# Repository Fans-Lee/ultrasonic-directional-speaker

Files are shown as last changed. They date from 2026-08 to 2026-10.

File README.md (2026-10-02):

**本项目没有参考任何开源项目，包括硬件实现、3D打印建模、软件实现。仅在作品构思阶段参考了一些现有成品的原理及作者反馈的问题。**

# 超声参量阵定向音响

> 文档版本：v5.3（2026-10-02）
> 当前实施基线：120 个换能器、12 路 TC4428 功率驱动、GPIO4 单相位扇出、40 kHz 复阻抗配组、二维机械云台和电脑视觉控制。

本项目将可听音频调制到 40 kHz 超声载波，通过 120 阵元同相发射获得窄声束，并由视觉跟踪和二维云台改变指向。当前版本不做电子相位转向或逐阵元聚焦。

```text
摄像头 → YOLO 人体检测 / ByteTrack 跟踪 → PI 控制 → 二维云台
音源   → 电脑端 DSP → 8 kHz PCM → ESP32 调制 → GPIO4
GPIO4  → SN74HC125 扇出 12 路 → 12 片 TC4428 → 12 组已配组的 TCT40-16T
```

120 只换能器逐只测量 40 kHz 复阻抗 `Z = R + jX`。分组时将容性与感性单元混合，并用导纳求和计算每组 10 只并联后的等效负载，使 12 路的虚部和幅值尽量接近。阵面上同时交错放置容性与感性单元，避免同类单元集中在局部区域。详细原理和施工要求见 [`docs/09-当前120阵元单GPIO接线.md`](docs/09-当前120阵元单GPIO接线.md)。
## 0.原创性说明

本项目没有参考任何开源项目，包括硬件实现、3D打印建模、软件实现。仅在作品构思阶段参考了一些现有成品的原理及作者反馈的问题。

## 1. 项目入口点

| 入口 | 文件 | 用途 |
|---|---|---|
| 桌面端主程序 | `src/vision_gimbal/__main__.py` | PySide6 UI、人体跟踪、云台、实时音频和声场显示 |
| 桌面端组合根 | `src/vision_gimbal/bootstrap.py` | 组装摄像头、YOLO、控制、串口、音频和 UI |
| 主配置 | `configs/vision_gimbal.toml` | 摄像头、模型、云台、串口、音频与可选声场参数 |
| ESP32 正式固件 | `src/full_size/full_size.ino` | 120 阵元单 GPIO 调制、二维舵机、Flash/实时音频和二进制协议 |
| 独立音频测试 | `utils/mic_stream_cli.py` | 不启动视觉和 UI，单独测试麦克风/电脑音频串流 |
| 文件串流诊断 | `utils/audio_stream_probe.py` | 把内置 PCM 原字节发给 ESP32，排查传输与调制问题 |
| Flash 音频转换 | `utils/wav_to_audio_header.py` | 把 PCM WAV 转为固件的 `audio_data.h` |
| 离线声学校准 | `utils/audio_calibration/calibrate.py` | 生成实验 PCM、拟合固定非线性模型、评估和预失真；不启动 Qt 或串口 |
| 单音录音试训 | `utils/audio_calibration/tone_pilot.py` | 对无配对输入的单音 WAV 拟合录音谐波轮廓；详见 `docs/16-单音录音试训.md` |
| 手机录音带通诊断 | `utils/audio_calibration/bandpass_wav.py` | 离线保留 250–3000 Hz，输出滤波 WAV 与频带电平报告；见 `docs/16-手机录音带通诊断.md` |

正式桌面端使用 `python -m vision_gimbal`。`src/cv_test_deprecated` 和 `src/esp32_s3_4x3_min_test_deprecated` 只是历史实现，不是当前入口。

## 2. 运行环境

电脑端建议使用：

- Windows 10/11；“静音无关回环”音源使用 Windows WASAPI；
- Python 3.11，项目支持 Python 3.10～3.12；
- [uv](https://docs.astral.sh/uv/)；
- UVC USB 摄像头；
- 连接硬件时需要 ESP32-S3 的 COM 口。

从仓库根目录同步锁定依赖：

```powershell
uv sync --locked --python 3.11
```

这会同时安装测试依赖。默认为 CPU 推理，并关闭可选的深度/声场分析。

### 可选推理后端

NVIDIA CUDA：

```powershell
uv sync --locked --python 3.11 --extra cuda
```

Intel XPU：

```powershell
uv sync --locked --python 3.11 --extra xpu
```

`cuda` 和 `xpu` 互斥，不能同时安装。`uv sync` 会以本次命令指定的 extra 同步环境，以后重新同步时应重复写出仍需要的 extra。

## 3. 启动桌面端

### 3.1 只运行视觉和云台仿真

在 PowerShell 中从仓库根目录执行：

```powershell
$env:PYTHONPATH = ".\src"
uv run python -m vision_gimbal --camera-index 0
```

这种方式不打开串口，但会运行摄像头、人体检测、目标选择和控制计算。如果第一个摄像头不是索引 `0`，修改 `--camera-index`。

### 3.2 连接 ESP32 完整启动

先烧录第 5 节的正式固件，然后确认 Windows 设备管理器中的 COM 口。例如 ESP32 是 `COM5`：

```powershell
$env:PYTHONPATH = ".\src"
uv run python -m vision_gimbal --camera-index 0 --serial-port COM5
```

可选的命令行覆盖：

```text
--config PATH       指定 TOML 配置
--serial-port COM5  指定 ESP32 串口
--baudrate 460800   覆盖串口波特率
--camera-index 0    覆盖摄像头索引
--device cpu        覆盖 YOLO 推理设备，也可使用 cuda:0 或 xpu:0
```

程序启动后：

1. 在追踪画面中单击人体框；
2. 单击“开始追踪”才会进入自动云台闭环；
3. 停止追踪时可用 `W/A/S/D` 手动控制；
4. 串口连接后选择音源，再单击“开始音频链路”。

### 连续调节音量

先烧录本仓库最新的 `src/full_size/full_size.ino` 固件，再启动桌面程序。串口连接并完成协议握手后，“音频与超声阵列”面板中的“主音量”滑块会启用；拖动它可在播放中调节麦克风、立体声混音或电脑声音，音频链路不会重启。默认音量为 50%，可在 `configs/vision_gimbal.toml` 的 `[audio.volume] default_percent` 修改。

0% 会在短暂渐变后关闭 GPIO4 超声 PWM；100% 等于原有最大音频调制幅度。滑块只衰减音频，不改变固定载波和测试纯音命令。界面的频谱与可选录音仍显示音量调节前的输入音频。若面板提示“固件需更新”，请先烧录新固件；旧固件的音频启动会被禁止，以免设定音量未生效。

不用桌面程序时，可在 460800 波特率串口监视器中发送 `V30` 后按回车，把内置 Flash 音频设为 30%；再发送 `P` 播放一次或 `L` 循环播放。`V0` 为音量静音，`V100` 恢复原有幅度，播放过程中也可调整。此命令仅在没有桌面端二进制协议会话时使用。音量静音不等于断开 12 V 电源。

默认音源是“电脑声音（静音无关回环）”。helper 不存在或其源码更新后，程序会自动调用 `utils/build_wasapi_process_loopback.ps1`，需要 MinGW-w64 `g++` 已在 `PATH` 中。也可提前编译：

```powershell
.\utils\build_wasapi_process_loopback.ps1
```

运行期间若 Windows 音频资源重配、helper 异常退出或 PCM 管道卡住，程序会自动重建回环采集和设备音频流；真实数字静音仍按活动门限关闭阵列 PWM。

不需要 WASAPI 进程回环时，可在 UI 中改选“麦克风”或“立体声混音”。用下列命令查看 PortAudio 设备名称：

```powershell
uv run python -m sounddevice
```

### 人物再次出现时的编号

视觉流水线会为合格的人体检测框提取服饰颜色特征，并在本次运行期间维护人物编号。新轨迹会立即抽样，最多取四次合格特征确定编号；已编号的轨迹默认每 1 秒再抽样一次，Kalman 预测框不会抽样。与历史人物连续两次匹配后，新轨迹会复用原编号。身份库默认保留离开画面人物 120 秒，程序关闭后清空。

这一路径只使用 CPU 和现有 OpenCV，不需要下载模型。它主要适用于同一摄像头、同一场次且衣着未变的情况；相似衣着、强遮挡或换装时可能认错或无法认回。人物未取得可靠特征前，框上显示 `ID ?`，不能选为自动追踪目标。目标丢失超过 0.8 秒后仍会停止自动追踪；人物被再次认出时可直接点击“开始追踪”，不会自行重启云台。参数在 `configs/vision_gimbal.toml` 的 `[vision.appearance]` 中调整。

## 4. 可选的深度与声场显示

此功能只做低频率可视化，不向云台、音频或 ESP32 发送指令。默认关闭。

1. 安装 OpenVINO 可选依赖：

   ```powershell
   uv sync --locked --python 3.11 --extra spatial
   ```

2. 确认模型目录 `models/yolo26n-depth_openvino_model` 存在。
3. 在 `configs/vision_gimbal.toml` 中设置：

   ```toml
   [spatial_field]
   enabled = true

   [spatial_field.depth]
   device = "intel:gpu"
   ```

如果需要同时使用 Intel XPU 跑人体跟踪，同步时同时传入两个 extra：

```powershell
uv sync --locked --python 3.11 --extra xpu --extra spatial
```

要在 CPU 上运行声场分析，还需将 `device` 改为 `cpu`，并设置 `allow_cpu_fallback = true`。

## 5. 编译和启动 ESP32 正式固件

仓库当前的唯一正式烧录入口是：

```text
src/full_size/full_size.ino
```

当前已验证的环境为 Arduino-ESP32 3.3.10。Arduino IDE 设置：

| 选项 | 值 |
|---|---|
| Board | `ESP32S3 Dev Module` |
| Upload Speed | `115200` |
| Flash Size | `16MB` |
| PSRAM | `8MB OPI`，以实际 ESP32-S3-WROOM-1-N16R8 菜单为准 |
| USB CDC On Boot | `Disabled`（当前 CH340X 链路） |
| 串口监视器 | `460800` baud |

打开 `.ino` 后编译并上传。上电后固件会把云台指令设为逻辑 `(0,0)`，但超声 PWM 保持关闭。在不连接桌面端时，可在串口监视器发送：

```text
A            连续固定载波
T            1 kHz 包络测试
P / L        播放一次 / 循环播放 Flash 音频
0 + 回车     停止 GPIO4 切换
H            显示完整帮助
```

详细命令、烧录和首次上电步骤见 [`src/full_size/README.md`](src/full_size/README.md)；120 阵元接线以 [`docs/09-当前120阵元单GPIO接线.md`](docs/09-当前120阵元单GPIO接线.md) 为准。

## 6. 独立诊断与音频工具

只测试麦克风到 ESP32 的音频链：

```powershell
$env:PYTHONPATH = ".\src"
uv run python .\utils\mic_stream_cli.py --serial-port COM5
```

使用当前 Flash PCM 测试串口传输：

```powershell
uv run python .\utils\audio_stream_probe.py --inspect-only
uv run python .\utils\audio_stream_probe.py --serial-port COM5 --processing raw --drive standard
```

把 PCM WAV 更换为固件内置音频：

```powershell
uv run python .\utils\wav_to_audio_header.py `
  .\input.wav `
  .\src\full_size\src\data\audio_data.h
```

生成后需要重新编译和烧录 ESP32。

## 7. 测试

从仓库根目录执行：

```powershell
uv sync --locked --python 3.11
uv run python -m pytest -q
uv run python -m compileall -q src utils
```

pytest 只收集 `tests/`，不会运行两个 `_deprecated` 历史目录。

## 8. 当前文档

- [原理、公式与能力边界](docs/01-原理与公式.md)
- [120 阵元整机与硬件实施](docs/02-系统方案与硬件.md)
- [当前软件架构与接口](docs/03-软件架构.md)
- [参考资料与证据边界](docs/04-开源参考.md)
- [实施计划与分工](docs/05-计划与分工.md)
- [采购、备件与到货验收](docs/06-采购清单.md)
- [版本验收、风险与演示](docs/07-版本阶梯与风险.md)
- [历史 12 阵元原型](docs/08-当前12阵元原型.md)
- [120 阵元单 GPIO 接线](docs/09-当前120阵元单GPIO接线.md)
- [当前项目完整数据流](docs/10-当前项目完整数据流.md)
- [视觉云台跟踪系统](docs/11-视觉云台跟踪系统.md)
- [实时音源与音频流协议](docs/12-实时麦克风与音频流协议.md)
- [实时音频传输排查](docs/13-实时音频传输排查.md)
- [连续音量控制设计与实现](docs/连续音量控制设计提案.md)
- [终审答辩 PPT](docs/show/超声参量阵视觉跟随定向音响-终审答辩.pptx)

`docs/01`～`docs/07` 已按当前 120 阵元机械转向基线重写；`docs/08` 是历史 12 阵元台架记录。任何电子相控研究都必须单独标记为未来方案，不得覆盖当前施工文档。

## 9. 安全边界

- 任何改线、插拔芯片或连接示波器之前，必须物理断开 12 V 功率电源。
- 串口 `0`、关闭音频链路或停止追踪都不等于物理急停。
- MG996R 舵机使用独立 5～6 V 大电流电源，与 ESP32 共地；不得从 ESP32 3.3 V 引脚供电。
- 不要把耳朵靠近阵面，不要用手机分贝 App 判断 40 kHz 超声暴露安全。
- 首次上电必须按正式固件 README 的单片、单换能器到全阵的顺序逐级验证。

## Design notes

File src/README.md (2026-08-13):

# ESP32-S3 + 12 只 TCT40-16T：4×3 最小测试版

## 1. 分组结论

把洞洞板的长边横放，形成 4 列、3 行：

```text
正面观察阵面

 CH1    CH2    CH3    CH4
  ○      ○      ○      ○
  ○      ○      ○      ○
  ○      ○      ○      ○
```

每一列 3 只并联，由一个 LEDC 输出通道和一个 TC4428A 驱动。因此是 **4 个 LEDC 输出通道，每个控制 3 只**。严格说并不是 4 个独立的 LEDC 外设：代码让 4 个输出通道共用 LEDC Timer 0，频率基准相同。

这样做的原因：

- 每个驱动器只承担 3 只换能器的并联电容，比 5 只更轻；
- 有 4 个横向相位自由度，后续可以做左右转向；
- 3 路各带 4 只只有 3 个横向相位自由度，而且每通道负载更大；
- 这只是 1D 横向转向原型，不等于已经能做 2D 定点聚焦。

今天先让 4 路全部同相。不要在没有示波器验证 `hpoint` 和更新毛刺前直接尝试相位扫描。

## 2. 今天需要的元件

| 元件 | 数量 | 说明 |
|---|---:|---|
| ESP32-S3 自制开发板 | 1 | GPIO4、5、6、7 |
| TCT40-16T 发射换能器 | 12 | 4 列，每列 3 只并联 |
| TC4428AEPA（DIP-8） | 4 | 每列 1 片 |
| DIP-8 插座 | 4 | 建议使用，先焊插座再插芯片 |
| 10～100 Ω、1/4 W 电阻 | 4 | 每路 GPIO 输入串联；现有10 Ω可用 |
| 10 kΩ、1/4 W 电阻 | 4 | 每路 TC4428 输入下拉 |
| 100 nF、≥25 V 陶瓷电容 | 4 | 每片 TC4428 的近端去耦 |
| 4.7～10 µF、≥25 V 电容 | 4 | 每片 TC4428 的近端储能 |
| 470 µF、≥25 V 电解电容 | 1 | 四路驱动板的 12 V 总入口 |
| 10～22 Ω、0.5 W 电阻 | 4 | 初次上电的输出串联限流/阻尼，可稍降声压 |
| 12 V/5 A 中心正适配器 | 1 | 本次远用不到 5 A，但电压合适 |
| 1～2 A 保险丝和匹配保险丝座 | 1 | 装在驱动板 12 V 分支；只有 5 A 也可先用，但保护较弱 |
| 开关、接线端子、洞洞板、导线 | 若干 | 电源线 18 AWG；逻辑/短输出线 22～24 AWG |

今天不需要：谐振电感、L298N、74HC125N、74LVC125AD、旋转平台、摄像头。短线台架仍按原方案，由 ESP32-S3 的 3.3 V GPIO 直接驱动 TC4428A 输入。现有一片 74AHCT125N 恰好能缓冲 4 路，但为保持本次最小版接线不变，暂不加入；如果后续加入，必须四路一起加入。

## 3. TC4428AEPA 逐针接线

缺口朝上，从左上角 1 脚开始逆时针编号：

```text
             缺口
          ┌────────┐
 NC    1 ─┤        ├─ 8  NC
 IN_A  2 ─┤TC4428A ├─ 7  OUT_A
 GND   3 ─┤        ├─ 6  VDD (+12 V)
 IN_B  4 ─┤        ├─ 5  OUT_B
          └────────┘
```

每一路完全相同：

```text
ESP32 GPIO ──10～100 Ω──┬── pin 2 IN_A
                    ├── pin 4 IN_B
                    └──10 kΩ── GND

12 V ─────────────── pin 6 VDD
GND  ─────────────── pin 3 GND

pin 6 VDD ──||── pin 3 GND    100 nF，贴近芯片
pin 6 VDD ──|(|─ pin 3 GND    4.7～10 µF，电解正极接 VDD

pin 7 OUT_A ──10～22 Ω── 列 A 母线 ──┬── 换能器 1 的 A 脚
                                  ├── 换能器 2 的 A 脚
                                  └── 换能器 3 的 A 脚

pin 5 OUT_B ───────── 列 B 母线 ──┬── 换能器 1 的 B 脚
                                  ├── 换能器 2 的 B 脚
                                  └── 换能器 3 的 B 脚
```

注意：

- pin 2 和 pin 4 必须接同一 GPIO；TC4428A 的两路输出因此互补；
- 换能器接在 `OUT_A` 与 `OUT_B` 之间，**两端都不能接 GND**；
- 串口命令 `0` 只会停止 40 kHz 切换。由于 TC4428A 是互补输出，静态输入时两输出仍可能一高一低；改线必须关闭驱动板 12 V，不能把软件停止当作断电；
- 四列的 A/B 输出母线互不相连；只有 `+12 V` 和 `GND` 共用；
- 12 只换能器朝向一致，同一侧引脚都标为 A；所有引脚都要焊，不靠孔的夹紧力导电；
- 每片芯片的 100 nF 必须贴近 pin 6 和 pin 3，不能只在电源入口放一个大电容；
- 10～22 Ω 先装在 OUT_A 一侧即可。示波器验证稳定后才考虑用 0 Ω 跨接旁路；
- pin 1、pin 8 悬空，不要接任何电源。

## 4. ESP32 到四路驱动的连接表

| 阵面列 | LEDC 通道 | 自制板引脚 | 接到 |
|---|---:|---|---|
| 最左列 CH1 | 0 | H4-4 / GPIO4 | 第 1 片 TC4428A 的 pin 2+4 |
| CH2 | 1 | H4-5 / GPIO5 | 第 2 片 TC4428A 的 pin 2+4 |
| CH3 | 2 | H4-6 / GPIO6 | 第 3 片 TC4428A 的 pin 2+4 |
| 最右列 CH4 | 3 | H4-7 / GPIO7 | 第 4 片 TC4428A 的 pin 2+4 |
| 公共地 | — | H4-22 / GND | 四片 TC4428A 的 pin 3 和驱动电源负极 |

GPIO 线尽量短，旁边配一根 GND；不要让逻辑线和四路差分输出长距离并排。

## 5. 12 V 电源怎么接

推荐电源树：

```text
12 V/5 A 适配器
  └─ DC5521（中心正）
      └─ 总开关/保险丝/星形分配
          ├─ 开发板 DC5521 输入
          └─ 1～2 A 分支保险丝 ── 四片 TC4428A 的 +12 V

适配器负极 ── 开发板 GND ── 四片 TC4428A GND（必须共地）
```

如果今天只有一个插头且来不及做外部分线，可以在万用表确认极性后，暂时从开发板标明的 `12 V 输出` 给这块 12 阵元小驱动板供电。本次负载较小，可以作为台架临时接法；最终 96 阵元不能让主电流经过开发板铜箔。上电前必须确认该端子相对 GND 为约 +12 V。

自制板的 Micro-USB 是 CH340X 烧录/串口链路，不应被当作开发板主电源。烧录时开发板本身也要由 DC5521 或 Type-C PD 电源口正常供电，二者选择一个，不要同时接入。

## 6. 烧录

Arduino IDE 选择：

- 开发板：`ESP32S3 Dev Module`
- Upload Speed：`115200`
- Flash Size：`16MB`
- PSRAM：`8MB / OPI PSRAM`（按当前板包菜单的等价选项）
- USB CDC On Boot：`Disabled`
- 串口：CH340X 对应的 COM 口

打开 `esp32_s3_4x3_min_test.ino`，开发板接 12 V，Micro-USB 接电脑，然后上传。上传后打开 115200 波特率串口监视器。

命令：

| 命令 | 行为 |
|---|---|
| `0` | 四路停止切换；改线前仍须切断驱动 12 V |
| `1`～`4` | 只开启对应的一列，40 kHz、50% 占空 |
| `A` | 四列同相开启，40 kHz、50% 占空 |
| `T` | 四列同相，运行 1 kHz 正弦包络测试 |
| `P` | 播放固件中的音频一次，播完自动停止 |
| `L` | 循环播放固件中的音频 |
| `H` | 显示帮助 |

上电默认关闭 PWM，不会自动发射。

### 6.1 直接试播内置旋律

当前 `audio_data.h` 配置了一个由固件生成的约2秒八音测试旋律。烧录后：

1. 先用 `1`～`4` 和 `T` 确认四路硬件正常；
2. 输入 `P`，播放测试旋律一次；
3. 输入 `L`，循环播放；
4. 随时输入 `0` 停止。

`A`只发连续40 kHz，人耳通常听不到。`P/L`才会把音频变成40 kHz载波的幅度包络。

### 6.2 换成自己的WAV音频

准备一段尽量短、语音清晰、没有强低音的未压缩PCM WAV。建议先用2～5秒语音，不要一开始放音乐。在本目录打开PowerShell并运行：

```powershell
python .\wav_to_audio_header.py .\我的音频.wav .\audio_data.h
```

如果电脑使用 `py` 启动Python：

```powershell
py .\wav_to_audio_header.py .\我的音频.wav .\audio_data.h
```

转换器会自动合并为单声道、重采样为8 kHz、转成8位无符号PCM、去除直流、归一化音量并增加短淡入淡出。转换器只接受未压缩PCM WAV，最长30秒；MP3、AAC需要先用音频软件导出为WAV。

生成后重新在Arduino IDE中编译并烧录，再发送 `P`。音频数据烧在ESP32 Flash里，播放时不依赖电脑持续传输；换音频需要重新生成头文件并烧录。8 kHz、8位、单声道每秒约占8 kB Flash。

### 6.3 这个播放功能实际做了什么

这不是普通扬声器的PCM输出，而是实验性的超声包络调制：

```text
8 kHz音频样本 → 正包络 → 改变40 kHz方波基波幅度
→ 四列TC4428差分驱动 → 超声阵列 → 空气非线性自解调
```

12只阵元、约24 Vpp且无谐振升压时，正确调制也可能只能听到很弱或失真的声音。是否听得到不能单独作为电路是否工作的判据。不要把耳朵贴近阵列；测试时让阵面朝向无人区域，先播放5～10秒并检查驱动器和输出电阻温升。

## 7. 必须按这个顺序上电

1. 不插 TC4428A、不接换能器，万用表查 +12 V 与 GND 无短路，并确认每个插座 pin 6 是 +12 V、pin 3 是 GND。
2. 只插第 1 片 TC4428A，先不接换能器。发送 `1`，测 GPIO4 为约 40 kHz。
3. 示波器分别测 pin 7 对 GND、pin 5 对 GND，应为约 0～12 V 且互补。
4. 示波器差分测量应使用 CH1/CH2 都以电路 GND 为参考，再做 `CH1-CH2` 数学运算。**不要把示波器地夹夹到 OUT_A 或 OUT_B。**
5. 先接 1 只换能器，工作 10 秒，断电检查 TC4428A 和 10～22 Ω 电阻是否发热。
6. 再扩到该列 3 只；通过后依次复制到 CH2～CH4。
7. 最后才发送 `A`。`T` 只用于包络链路试验，不以“耳朵听见”为通过条件。

理想情况下，12 V 供电的 OUT_A 与 OUT_B 差分接近 24 Vpp，但负载、驱动内阻和 10～22 Ω 电阻会使实测值降低。40 kHz 超声听不见并不代表没有输出；使用示波器加接收型 40 kHz 换能器检查，手机麦克风/分贝 App 不可靠。

## 8. 这版能证明什么、不能证明什么

能证明：

- ESP32-S3 能稳定产生四路 40 kHz；
- TC4428A 的互补差分驱动、电源和 12 只阵面接线正常；
- 四列单独开关和同相合成正常；
- 简单包络能从代码传到超声载波。

不能证明：

- 已经完成语音播放；
- 已经完成定点聚焦或视觉跟踪；
- 12 只、约 24 Vpp 的小阵面一定能产生明显的空气自解调可听声；
- 当前 LEDC 相位更新无毛刺。后续必须用示波器校准，再增加静态相位表。

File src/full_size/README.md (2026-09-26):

# ESP32-S3 120 阵元单 GPIO 正式固件

本工程对应 `docs/09-当前120阵元单GPIO接线.md` 定义的比赛整机：GPIO4 经 4 片 SN74HC125N 两级扇出为 12 路，再由 12 片 TC4428A 分别驱动 10 只并联的 TCT40-16T，共 120 只换能器。

它从现已归档为 `esp32_s3_4x3_min_test_deprecated` 的早期台架提取了音频、调制和定时部分，并删除 4×3 原型专用的四通道控制。这里的“12 路”是外部硬件功率支路，不是 12 个软件相位通道；全部支路接收同一个 GPIO4 波形。

## 1. 工程边界

本固件负责：

- GPIO4 上的 38～42 kHz 单路载波；
- 固定载波、20～3000 Hz 包络测试和 Flash PCM 播放；
- DSB-AM / SRAM 调制；
- RAW / LOUD 音频电平处理；
- STANDARD / BOOST 包络深度；
- 8 kHz GPTimer 调度、过期样本跳过和时序警告；
- GPIO6左右、GPIO5上下的MG996R二维云台控制；
- 上电回到逻辑`(0,0)`并保持超声静音；
- 通过二进制协议接收电脑端 8 kHz、8-bit、单声道实时 PCM；
- 运行错误停止超声切换。

本固件不负责：

- GPIO5～GPIO7的超声逐组输出；
- 电子相位转向、聚焦和逐组增益；
- 摄像头、目标识别和PC视觉；
- 云台机械限位、零点偏置和视觉闭环标定；
- 切断12 V功率电源。

摄像头和PC视觉仍属于独立控制链；它们通过串口向本固件发送`(左右,上下)`目标角度。本版冻结GPIO6为左右、GPIO5为上下，两轴逻辑范围均为-90°～90°，但机械限位、实际零位和方向仍须在装机后标定。

## 2. 目录

```text
full_size/
├─ full_size.ino                 Arduino 启动入口
├─ README.md
└─ src/
   ├─ app/                       串口、命令队列、FreeRTOS和GPTimer
   ├─ driver/                    GPIO4和单LEDC通道
   ├─ modulation/                包络、DSB-AM、SRAM和PCM处理
   └─ data/audio_data.h          8 kHz、8-bit、单声道Flash PCM
```

Arduino会递归编译 sketch 内层的 `src` 目录。

## 3. 与最小测试相比删除的内容

以下4×3原型遗留没有进入本工程：

- `kChannelCount = 4`和GPIO4/5/6/7数组；
- `setChannelDuty()`、`setAllDuty()`和四路更新循环；
- `1～4`单独选列命令；
- `CH1～CH4`、`four columns`和`4x3 smoke test`提示；
- 四路更新同步性的无效负担；
- `audio_data.h`无真实PCM时生成八音旋律的回退分支。

保留的内容都有120阵元用途：载波调谐、纯音测试、PCM播放、DSB/SRAM、RAW/LOUD、STANDARD/BOOST、中心对齐PWM和积压处理。

## 4. 信号与功率路径

```text
audio_data.h / PC实时PCM / 测试正弦
        ↓ 8 kHz
调制包络 → 反正弦映射 → LEDC duty + hpoint
        ↓
GPIO4：默认40 kHz、10-bit、中心对齐PWM
        ↓
U0 → U1/U2/U3：12路同相3.3 V逻辑
        ↓
P1～P12：TC4428A互补差分输出
        ↓
12组 × 10只并联TCT40-16T
```

GPIO4只传递时序；SN74HC125由3.3 V供电；阵列能量来自12 V功率电源。完整逐针接线和上电顺序以 `../../docs/09-当前120阵元单GPIO接线.md` 为准。

## 5. 串口命令

应用串口为460800波特率。未建立二进制会话前仍保留旧的字母命令，数字命令需要回车或空格结束；实时音频和云台控制使用 `../../docs/12-实时麦克风与音频流协议.md` 定义的二进制协议。

| 命令 | 功能 |
|---|---|
| `0` + 回车 | 停止GPIO4切换 |
| `A` | 完整阵列固定载波，50%占空比 |
| `T` | 1 kHz包络测试 |
| `20`～`3000` + 回车 | 指定可听测试频率 |
| `D` / `S` | 下一次PCM使用DSB-AM / SRAM |
| `R` / `E` | 下一次PCM使用RAW / LOUD处理 |
| `N` / `B` | 下一次纯音或PCM使用STANDARD / BOOST包络 |
| `-`、`[` | 载波降低100 Hz，最低38 kHz |
| `+`、`]` | 载波提高100 Hz，最高42 kHz |
| `C` | 恢复40 kHz |
| `F` | 打印实际载波频率 |
| `P` / `L` | PCM播放一次 / 循环播放 |
| `V0`～`V100` + 回车 | 调节内置和实时 PCM 主音量；0 关闭超声 PWM，100 为原有幅度 |
| `(左右,上下)` | 设置云台逻辑角度，例如`(-10,30)`；两轴范围均为-90°～90° |
| `H` / `?` | 打印帮助 |

`D/S/R/E/N/B`只选择下一次播放参数，不会改变正在运行的PCM或纯音。`V` 音量可以在 PCM 播放中调整，约 40 ms 内渐变；固定载波与测试纯音不受它影响。独立使用时例如先发送 `V30` 回车，再发送 `P`；播放中也能发送新的 `V` 值。上电默认 100%，桌面主程序连接后会发送自己的默认值（当前 50%）。0 音量不会物理断开 12 V。

## 6. 调制参数

音频样本归一化为：

```text
s = (sample - 128) / 128
```

调制公式：

```text
DSB-AM: E = b + d·s
SRAM:   E = sqrt((b+d)·(b+d·s))
PWM:    duty_ratio = asin(E) / π
```

| 驱动模式 | `b` | `d` | DSB理论包络范围 |
|---|---:|---:|---:|
| STANDARD | 0.45 | 0.40 | 0.05～0.85 |
| BOOST | 0.50 | 0.48 | 0.02～0.98 |

LEDC周期为1024 counts，最大duty为512。驱动层设置：

```text
hpoint = (1024-duty)/2
```

使脉冲中心尽量固定，降低改变占空比时产生的附加相位调制。

## 7. 更换Flash音频

在仓库根目录执行：

```powershell
py .\utils\wav_to_audio_header.py `
  .\input.wav `
  .\src\full_size\src\data\audio_data.h
```

转换器接受最长30秒的未压缩PCM WAV，并进行单声道合并、8 kHz重采样、去直流、峰值归一化和首尾淡入淡出。生成后需要重新编译和烧录。

## 8. 烧录设置

Arduino IDE建议：

- Board：`ESP32S3 Dev Module`；
- Upload Speed：`115200`；
- Flash Size：`16MB`；
- PSRAM：按ESP32-S3-WROOM-1-N16R8实际配置选择8MB OPI；
- USB CDC On Boot：按当前CH340X烧录链路选择`Disabled`；
- 串口监视器：460800波特率。

打开 `full_size.ino` 编译和烧录。上电后云台回到`(0,0)`，超声输出保持关闭；发送 `P/L` 可播放内置音频，或由电脑建立协议会话后开始实时音频流。

舵机不能由ESP32的3.3V脚供电。MG996R使用独立5～6V大电流电源，两个舵机电源地与ESP32的PUBLIC GND共地；GPIO6只接左右舵机信号，GPIO5只接上下舵机信号。

## 9. 首次上电顺序

1. 不插TC4428、不接换能器，检查12 V、3.3 V和GND无短路。
2. 只给SN74HC125上3.3 V，发送`A`，确认12路逻辑输出同相。
3. 暂不接换能器，每次只插一片TC4428，检查OUT_A和OUT_B互补。
4. 先给一片TC4428接1只换能器，再扩到该组10只。
5. 单组通过后逐组增加，最后才连接120只。
6. 首次满阵播放使用STANDARD和RAW，短时间运行并记录电流、波形和温升。
7. 基线通过后再比较LOUD、BOOST和SRAM。

普通示波器测差分输出时，两个探头地夹都接PUBLIC GND，再用数学通道计算`CH1-CH2`。禁止把地夹接到TC4428的pin 5或pin 7。

## 10. 安全边界

- 串口`0`只停止40 kHz切换，不会断开12 V。
- TC4428输入静止时，两个输出仍可能一高一低。
- 改线、插拔芯片和连接示波器前必须物理断开12 V。
- 不把耳朵靠近阵面，不用手机分贝App判断40 kHz暴露安全。
- 120阵元必须从单片、单只负载逐步扩展，不能第一次上电就接满阵列。
- 本固件不能代替保险丝、总开关、星形配电、温升监测和合格的超声测量。

## 11. 当前音频链的已知限制

- PCM为8 kHz、8-bit、单声道，理论音频上限低于4 kHz；
- Flash和实时流仍由任务逐样本更新LEDC，没有载波同步DMA；
- 实时流固定为8 kHz、8-bit、单声道，依赖电脑端预处理和有界缓冲；
- GPTimer调制更新没有与LEDC载波边界硬件锁存；
- PWM占空比调制可能产生非定向的机械可听泄漏；
- DSB-AM和SRAM的实际失真必须在相同可听基波声压下测量；
- 手机麦克风不能证明40 kHz声压或定向可听声性能。

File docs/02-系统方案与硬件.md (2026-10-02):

# 02 · 120 阵元整机与硬件实施说明

> 版本：v2.1
> 日期：2026-10-02
> 施工细节以 [09-当前120阵元单GPIO接线.md](09-当前120阵元单GPIO接线.md) 为准

当前整机不是旧的 96 阵元电子相控方案。它使用 120 个同相阵元，由二维机械云台改变指向。

## 1. 整机架构

```text
Windows 电脑
├─ USB 摄像头 → YOLO/ByteTrack → 目标角度
├─ 麦克风/电脑音频 → DSP → 8 kHz PCM
└─ USB 串口 → ESP32-S3
                   ├─ GPIO6 → 水平 MG996R
                   ├─ GPIO5 → 俯仰 MG996R
                   └─ GPIO4 → SN74HC125 两级扇出
                                  → 12 路同相逻辑
                                  → 12 片 TC4428A
                                  → 12 组 × 10 只 TCT40-16T
```

固件、云台和音频共用一个 ESP32-S3，但三条供电链不能混淆：

| 链路 | 电源 | 用途 |
|---|---|---|
| 逻辑 | ESP32 3.3 V | ESP32 和 4 片 SN74HC125 |
| 超声功率 | 12 V / 5 A | 12 片 TC4428A 和 120 个换能器 |
| 云台 | 独立 5～6 V 大电流电源 | 2 个 MG996R 舵机 |

三者必须共地，但功率回流不得先经过 ESP32 排针。

## 2. 阵面和功率分组

- 换能器：120 个 `TCT40-16T`；
- 阵面：正六边形蜂窝排布；
- 电气分组：12 组，每组 10 只并联；
- 配组依据：逐只测量 40 kHz 复阻抗，将容性与感性单元混合分配；
- 每组使用 1 片 `TC4428AEPA` 互补差分驱动；
- 12 组接收完全相同的 GPIO4 波形。

换能器必须保持一致的机械极性和安装方向。“没有直流正负极”不等于“可以随机反接”；反向单元会在阵列合成时产生抵消。

## 3. GPIO4 两级扇出

4 片 `SN74HC125N` 统一由 3.3 V 供电：

```text
GPIO4 → U0 的 3 个启用通道
      ├─→ U1 的 4 个通道 → P1～P4
      ├─→ U2 的 4 个通道 → P5～P8
      └─→ U3 的 4 个通道 → P9～P12
```

重要边界：

- `OE` 低有效，使用中的通道必须明确拉低；
- GPIO4 入口使用 10 Ω 串联和 10 kΩ 下拉；
- U1～U3 的每个输出到 TC4428 输入使用 47 Ω 串联和 10 kΩ 下拉；
- 逻辑扇出只传递时序，不为换能器提供功率。

逐针连接、12 路编号和未用通道处理不在本章重复，必须按文档 09 施工。

## 4. TC4428A 单组驱动

每片 TC4428A 的两个输入接到同一个缓冲后逻辑信号，两个输出互补。10 只换能器并联后接在 `OUT_A` 和 `OUT_B` 之间。

每个功率单元至少包含：

- TC4428AEPA 和 DIP-8 插座；
- 芯片近端 100 nF 陶瓷去耦；
- 芯片近端 10 µF、耐压至少 25 V 储能电容；
- 一个 4.7 Ω / 2 W 输出阻尼电阻；
- 明确的 12 V、地、输入和差分输出标记。

当前整机已完成换能器负载配组。对每只换能器在 40 kHz 处测得 `Z_i = R_i + jX_i`，再按并联关系计算每组等效导纳与阻抗：

```text
Y_group = Σ(1 / Z_i)
Z_group = 1 / Y_group
```

分组时混合 `X < 0` 的容性单元和 `X > 0` 的感性单元，使 12 路的等效虚部尽量接近零，同时平衡等效阻抗幅值和支路电流。这是基于实测的离散配组，不能用单只换能器的标称电容或历史电感值代替。`4.7 Ω` 仍是输出阻尼和限流元件，不承担这一配组功能。

## 5. 电源和配电

12 V 采用星形入口和三条功率分支：

```text
12 V 总入口
├─ 分支 A → P1～P4
├─ 分支 B → P5～P8
└─ 分支 C → P9～P12
```

洞洞板细铜箔不能作为整机大电流母线，应使用粗铜线补强。总入口需要开关和保险丝；三条分支各配置 470 µF 局部储能，总入口配置 1000 µF。大电容不能代替每片芯片的近端去耦。

| 位置 | 建议线径 |
|---|---|
| 12 V/GND 外部活动主线 | 18 AWG 柔软硅胶线 |
| 板内三条功率分支 | 18～20 AWG |
| 单片 TC4428 与换能器组 | 20～22 AWG，尽量短 |
| 3.3 V、GPIO4 及逻辑线 | 24～26 AWG |

## 6. 二维云台

| 轴 | ESP32 信号 | 固件逻辑范围 |
|---|---|---:|
| 水平 pan | GPIO6 | -90°～90° |
| 俯仰 tilt | GPIO5 | -90°～90° |

这是协议和固件范围，不是装机后的安全机械范围。电脑配置中还有更窄的软件限位，必须按实物零点、方向、线束和结构干涉重新校准。

MG996R 不得由 ESP32 3.3 V 或 USB 口供电。云台电源线和摄像头 USB 线应作为独立活动线束，在转轴附近留出弯曲余量。

## 7. 摄像头与电脑

- 摄像头使用 UVC USB 接口；
- ESP32 不接收视频，也不运行 YOLO；
- 电脑只向 ESP32 发送云台角度、音频和控制帧；
- 摄像头必须与阵面刚性固定，否则瞄准误差会随运动改变。

## 8. 施工与上电门禁

1. 检查器件型号、批次、方向和标记。
2. 只焊电源母线，断电检查 12 V 与 GND 无短路。
3. 只上 3.3 V 逻辑，验证 12 路缓冲输出同相。
4. 每次只插一片 TC4428，不接换能器验证互补输出。
5. 单片先接 1 只换能器，再增加到 10 只，记录电流、波形和温升。
6. 装入已确认的 40 kHz 配组，不得在支路之间随意调换换能器。
7. 单组通过后逐组增加，最后才连接 120 只。
8. 云台首次动作前使用小角度软件限位，确认没有机械干涉。

推荐上电顺序是先稳定 3.3 V 逻辑，后接 12 V 功率；断电顺序相反。串口停止、软件静音和停止跟踪都不是物理断电。

## 9. 硬件交付物

- 带编号的 12 路逻辑、功率和阵元映射表；
- 120 只换能器的 40 kHz `R/X` 原始数据、12 组分组表与每组等效阻抗；
- 正反面接线照片和线束标签；
- 无负载、单只、10 只和全阵的原始波形；
- 三条功率分支的电流和温升记录；
- 云台实际零点、方向和安全软件限位；
- 断电、保险丝更换和故障回退说明。

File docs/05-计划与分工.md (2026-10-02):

# 05 · 当前实施计划、分工与集成规则

> 版本：v2.1
> 日期：2026-10-02
> 基线：120 阵元单 GPIO、40 kHz 复阻抗配组、机械云台、电脑视觉和实时音频

本计划不再包含旧的 96 阵元、8/16 路电子相控路线。电子转向或聚焦若恢复，应单独立项，不得在当前整机调试中临时混入。

## 1. 项目管理原则

1. 以可复现验收门为进度，不以“代码写完”或日期代替通过。
2. 一次只改变一个关键变量：供电、负载数量、载波、调制、音源或控制参数。
3. 软件、逻辑、功率、声学和机械逐级集成，不第一次上电就接满 120 阵元。
4. 当前行为以源码和文档 09～13 为准，旧原型只作历史参考。
5. 每项性能结论必须指向原始数据、配置、固件提交和测量条件。
6. 功能失败时回退到最近一个通过验收的状态，不在现场继续叠加改动。

## 2. 工作包

| 工作包 | 内容 | 主要输出 | 验收依据 |
|---|---|---|---|
| WP1 桌面软件 | UI、视觉、控制、实时音频、配置 | `src/vision_gimbal`、测试 | 全量测试、仿真运行、状态日志 |
| WP2 ESP32 固件 | 协议、缓冲、调制、GPIO4、舵机 | `src/full_size` | 编译记录、GPIO/串口测试 |
| WP3 逻辑扇出 | U0～U3 和 12 路编号 | 接线、波形、映射表 | 12 路同相和幅值检查 |
| WP4 功率驱动 | P1～P12、去耦、阻尼、配电 | 驱动板和温升记录 | 单片到 12 片逐级测试 |
| WP5 阵面与配组 | 120 阵元、40 kHz 复阻抗、极性、安装、云台 | 阵元数据、配组表、阵面和结构图 | 12 组等效阻抗、连通、极性和干涉检查 |
| WP6 声学测量 | 方向图、频响、失真和噪声 | 原始数据、图表、条件说明 | 可复现测量流程 |
| WP7 集成与答辩 | 完整启动、回退、安全和演示 | 演示包、检查表、备份 | 冷启动演练和故障回退 |

## 3. 三人参考分工

### A：软件与嵌入式

- 维护 `src/vision_gimbal`、`src/full_size`、协议和配置；
- 保证 `uv.lock`、测试和启动文档可复现；
- 输出 GPIO4、GPTimer、串口状态和错误计数的解释；
- 不在未经硬件确认时自行扩大电压、调制度或舵机范围。

### B：电路与电源

- 负责 SN74HC125、TC4428、12 V 配电、保险丝、去耦和阻尼；
- 逐级保存逻辑和差分波形、输入电流与温升；
- 确认示波器接地方式和改线断电流程；
- 按实际 40 kHz 支路等效阻抗核对负载与驱动安全性，不用标称值代替实测。

### C：阵面、机械和测量

- 负责 120 个换能器编号及 40 kHz `R/X` 测量，按容性/感性和等效负载完成 12 组分配；
- 负责极性、焊接、容性/感性阵元空间交错和结构固定；
- 负责云台重心、活动线束、限位和相机刚性安装；
- 执行方向扫描、频响、录音和环境记录；
- 维护实物照片、BOM 批次和答辩原始证据。

人员数量变化时可以合并角色，但验收责任不能消失。

## 4. 阶段门

### G0：仓库和接口可复现

- 根 README 的安装和启动命令可执行；
- `uv lock --check` 通过；
- 全量 Python 测试和语法检查通过；
- 当前正式入口只有 `vision_gimbal` 和 `src/full_size/full_size.ino`。

### G1：桌面端无硬件运行

- 摄像头打开并显示画面；
- YOLO/ByteTrack 输出人物轨迹；
- 显式选择、开始/停止跟踪和 WASD 行为正确；
- 未配置串口时不驱动硬件且 UI 不崩溃。

### G2：ESP32 低能量逻辑

- 固件使用锁定的 Arduino-ESP32 版本编译；
- 上电默认 GPIO4 关闭；
- `A/T/P/L/0/H` 台架命令行为正确；
- 二进制 HELLO、ACK、STATUS 和云台帧正确；
- 只上 3.3 V 时验证 GPIO4 与 12 路缓冲输出。

### G3：单功率通道

- 不接换能器时验证 TC4428 两输出互补；
- 单只换能器短时运行通过；
- 逐步增加到单组 10 只，记录波形、电流和温升；
- `RAW + STANDARD + DSB-AM` 作为首次音频模式。

### G4：12 路与 120 阵元

- P1～P12 逐片通过 G3；
- 三条 12 V 分支压降和回流合理；
- 120 个阵元极性、编号和 40 kHz 配组与实测记录及文档 09 一致；
- 12 组并联等效阻抗已由各单元导纳求和复核，组间差异在实测允许范围内；
- 全阵先短时运行，再逐步增加持续时间。

### G5：实时音频

- 内置 Flash PCM 可稳定播放；
- 同一 PCM 字节经串口发送时行为可对照；
- 麦克风、立体声混音和进程回环分别测试；
- CRC、gap、overrun、underrun、timer skip 和 host drop 有记录；
- 静音门能够停止无内容时的 PWM。

### G6：视觉云台闭环

- 相机与阵面固定关系稳定；
- 水平、垂直方向和软限位经过实物校准；
- 目标丢失后不自动切换到其他人物；
- 线束在全范围运动中不拉扯、不卷入结构；
- “停止追踪”与物理急停的边界清楚。

### G7：声学和长时间运行

- 在固定距离完成方向扫描；
- 保存可听频响和失真对照；
- 长时间运行记录温升和协议计数；
- 所有对外性能数字能追溯到原始文件。

## 5. 集成顺序

```text
软件单测
→ 摄像头/无串口仿真
→ ESP32 协议与 GPIO4
→ 12 路 3.3 V 逻辑
→ 单片 TC4428
→ 单组 10 只
→ 12 组 / 120 只
→ Flash 音频
→ 实时音频
→ 云台
→ 视觉闭环
→ 声学和长时验收
```

若某一级失败，先断开其后的模块，再在最近通过的边界上排查。

## 6. 变更控制

以下变更必须单独记录并重新跑受影响的验收门：

- GPIO、LEDC、GPTimer、串口波特率或协议布局；
- 每片 TC4428 的负载数量或供电电压；
- SN74HC125 型号、供电或扇出树；
- 音频采样率、包长、缓冲和超时；
- 调制公式、LOUD/BOOST 参数；
- 舵机补偿、方向和软限位；
- 相机内参、分辨率或安装位置；
- 模型文件、推理后端或依赖锁。

提交说明至少包含：改了什么、为什么改、影响哪些验收门、如何回退。

## 7. 数据和文件规则

每份测量记录至少包含：

- 日期、操作者和 Git 提交；
- 固件入口和 Arduino-ESP32 版本；
- `vision_gimbal.toml` 或关键配置快照；
- 电源、负载、音源、调制模式和测试时长；
- 仪器型号、带宽、探头连接和测点；
- 原始数据文件，而不只是截图或结论。

运行日志和录音可先放在忽略的 `output/` 或 `work/` 中；一旦用于报告，应筛选、去除机器绝对路径并移入受版本控制的证据目录。

## 8. 功能冻结和演示

演示前至少完成一次从断电状态开始的完整演练：

1. 检查接线、保险丝、云台活动范围和人员位置；
2. 烧录已验证固件并保存二进制/版本信息；
3. 使用锁定依赖启动桌面程序；
4. 先验证视觉和云台，再接通 12 V 功率；
5. 从低能量模式验证音频；
6. 演示结束先断 12 V，再关闭逻辑和软件。

演示包应包含内置 Flash 音频、离线视频或截图、配置备份、USB 线、备用保险丝、备用 TC4428A 和可直接回退的稳定固件。

## 9. 完成定义

“完成”同时要求：

- 源码、依赖锁和文档一致；
- 软件测试与固件编译可复现；
- 硬件按逐级流程通过；
- 性能结论有原始测量；
- 安全和故障回退经过演练；
- 未来功能没有被写成当前能力。

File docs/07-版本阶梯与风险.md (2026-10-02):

# 07 · 当前版本验收、风险、安全与演示

> 版本：v2.1
> 日期：2026-10-02
> 本文件定义“完成”的证据，不预先宣称尚未实测的性能

## 1. 版本阶梯

### V0：软件与低能量台架

- Python 依赖、测试和入口可复现；
- 摄像头和人物跟踪可在无串口模式运行；
- ESP32 上电默认静音；
- GPIO4、12 路 3.3 V 扇出和二进制协议通过；
- 不连接 12 V 功率或完整阵面。

### V1：120 阵元声学基线

- 12 片 TC4428A 逐片通过；
- 120 个换能器已测量 40 kHz 复阻抗，极性、配组和连接与实测表及文档 09 一致；
- 固定载波、测试包络和 Flash PCM 可运行；
- 完成基本方向扫描、频响和温升记录；
- 不要求电脑、摄像头或实时音频即可演示内置音频。

### V2：完整交互系统

- 共享串口同时承载云台、音频和状态；
- 麦克风、立体声混音和 WASAPI 进程回环至少各完成一次验收；
- 用户显式选人后，机械云台可跟踪目标；
- 目标丢失、串口断开和静音时行为可解释；
- 连续运行期间错误计数、温升和线束运动受控。

### V3：可选分析与未来研究

- OpenVINO 深度和相对声场属于显示功能，不参与控制；
- 电子相位转向、聚焦和逐通道校准尚未实现；
- V3 功能失败不得影响 V1/V2 的稳定演示。

## 2. 当前状态记法

每个验收项只允许使用以下状态：

| 状态 | 含义 |
|---|---|
| `NOT_RUN` | 尚未执行 |
| `PARTIAL` | 只完成部分条件或证据不完整 |
| `PASS` | 按本文件条件完成并保存证据 |
| `FAIL` | 已执行但未达到判据 |
| `BLOCKED` | 缺少仪器、器件或外部条件 |

禁止用“代码存在”“肉耳听到”或“以前好像成功过”代替 `PASS`。

## 3. 软件验收

从仓库根目录执行：

```powershell
uv sync --locked --python 3.11
uv lock --check
uv run python -m pytest -q
uv run python -m compileall -q src utils
```

还应分别验证：

- `python -m vision_gimbal --help`；
- 无串口启动；
- 指定实际 `--serial-port` 启动；
- `audio_stream_probe.py --inspect-only`；
- `wav_frequency_squared_compensation.py --help`；
- 默认配置关闭可选声场时，不要求 OpenVINO。

测试数量会随版本变化，文档不固定写死通过项数；以当前命令输出和提交记录为准。

## 4. 电气验收

### 4.1 只上 3.3 V

| 测试 | 判据 |
|---|---|
| 上电默认状态 | GPIO4 不持续切换 |
| 固定载波 | GPIO4 为目标频率，默认约 40 kHz |
| 调频 | 38～42 kHz、100 Hz 步进命令有效 |
| 第一级扇出 | U0 三路输出逻辑正确 |
| 第二级扇出 | U1～U3 共 12 路同相、幅值合理 |
| 停止 | `0` 后 GPIO4 停止切换 |

### 4.2 单片 TC4428A

1. 暂不接换能器，使用限流供电。
2. 分别测 `OUT_A`、`OUT_B` 对公共地，应为互补波形。
3. 两个示波器探头地夹都接公共地，再用数学通道计算差分。
4. 禁止把示波器地夹接到 `OUT_A` 或 `OUT_B`。
5. 接 1 只换能器短时运行，断电检查温升。
6. 逐步扩到该组 10 只并重复记录。

### 4.3 十二路和全阵

- P1～P12 单独验证，不跳过中间通道；
- 根据 `Y_group = Σ(1/Z_i)` 复核每组 10 只并联后的等效阻抗，不直接相加单只阻抗；
- 确认容性与感性单元在 12 组内混合、在阵面上交错放置；
- 对三条功率分支分别记录压降和电流；
- 检查 12 路传播延时和同相程度；
- 先运行 `RAW + STANDARD + DSB-AM`，再比较高能量模式；
- 每增加负载或持续时间后都检查 TC4428、阻尼电阻、换能器和连接器温升。

## 5. 音频和协议验收

### 5.1 Flash 与串口对照

使用同一份 `src/full_size/src/data/audio_data.h`：

1. 播放固件内置 PCM；
2. 用 `audio_stream_probe.py` 发送同一字节；
3. 两条路径选择相同的 RAW/LOUD、STANDARD/BOOST 和 DSB-AM/SRAM；
4. 比较缓冲状态、错误计数、GPIO4 波形和可听输出。

这能隔离传输问题和前端 DSP 差异，但不能替代真实 UART、GPTimer 和声学测量。

### 5.2 实时音源

每种音源至少记录：

- `connected` 和 `status_age_ms`；
- `buffer_fill_samples`；
- `underrun`、`overrun`、`crc`、`gap`、`skip`；
- `host_drop`、采集设备和采样率；
- 处理模式、运行时间和是否同时运行视觉。

进程回环还应验证：物理扬声器静音不影响数字捕获；数字静音持续后 ESP32 PWM 停止；恢复音频后重新预缓冲。

## 6. 云台与视觉验收

1. 不装阵面或采用小角度软限位验证两个舵机方向。
2. 校准相机水平/垂直视场角、瞄准偏移和云台零点。
3. 验证 UI 点击映射与实际人物框一致。
4. 验证只有“开始追踪”后的活动目标驱动云台。
5. 自动跟踪时 WASD 不得叠加控制。
6. 目标暂时丢失时可短期保持/预测；超过释放时间后停止自动跟踪。
7. 验证全范围内线束无拉扯、夹线和结构碰撞。

UI 的指令角度不是舵机反馈。没有编码器时，不能宣称闭环控制了真实机械角度。

## 7. 声学测量

### 7.1 固定条件

每次对比固定：

- 阵面位置、高度和角度；
- 测量距离、测点间隔和房间环境；
- 载波频率、音频内容和调制模式；
- 供电电压和预热时间；
- 麦克风、前端增益、采样率和分析窗口。

### 7.2 方向扫描

在固定半径或固定平面上按等间距测点，至少保存正前方和左右两侧数据。报告应区分：

- 40 kHz 超声载波方向性；
- 自解调可听声方向性；
- 结构直接辐射或电子设备产生的非定向可听泄漏。

不能用人在不同位置的主观响度或手机 App 数字替代正式方向图。

### 7.3 频响和失真

- 使用多个可听频率或扫频，保持载波和测点不变；
- 比较 RAW/LOUD、STANDARD/BOOST、DSB-AM/SRAM 时控制可听基波声压；
- 记录基波、谐波、噪声底和可能的 40 kHz 混叠；
- 麦克风或前端自身的超声互调可能制造假可听成分，应做遮挡、断载和距离对照。

## 8. 安全边界

- 40 kHz 听不到不等于没有能量或没有风险；
- 不把耳朵、手或测量麦克风长时间贴近阵面；
- 调整接线、插拔芯片、移动探头前物理断开 12 V；
- 软件 `0`、停止音频或停止追踪都不能代替 12 V 急停；
- 舵机堵转、结构碰撞或线束缠绕时立即切断舵机电源；
- 未使用合适仪器前，不公布超声暴露安全结论。

## 9. 风险登记表

| 风险 | 可能性 | 影响 | 监测 | 缓解/回退 |
|---|---|---|---|---|
| 换能器极性或分组错误 | 中 | 高 | 分组接收测试、方向图 | 逐组断开并重新标记 |
| 40 kHz 配组记录与实物不一致 | 中 | 高 | 逐只编号、`R/X`、组号和位置核对 | 断电后按原始数据恢复配组并复测组阻抗 |
| 12 路扇出边沿差异 | 中 | 中/高 | 逻辑分析仪、示波器 | 缩短信号线、检查去耦和扇出 |
| TC4428 或阻尼电阻过热 | 中 | 高 | 电流与温升记录 | 降低负载/调制度/运行时间 |
| 电源回流干扰 ESP32 | 中 | 高 | 复位、串口错误、电源纹波 | 星形地、粗线、分支去耦 |
| UART 欠载或数据缺口 | 中 | 中 | under/gap/crc/host_drop | 排查端口、调度和队列，不盲目增益 |
| GPTimer 过期样本 | 低/中 | 中 | skip 计数、GPIO 更新间隔 | 减少阻塞，保持播放任务优先级 |
| PWM 造成机械可听泄漏 | 高 | 中/高 | 遮挡和近场对照 | 降低调制度，调查替代调制后端 |
| 云台方向或零点错误 | 中 | 高 | 小角度空载测试 | 收紧软限位并重新标定 |
| 目标丢失后误跟人 | 低 | 高 | 会话和丢失测试 | 保持显式选择、超时停止策略 |
| OpenVINO/声场功能过载 | 中 | 低/中 | 推理时间和 overrun | 保持可选、关闭支路，不影响主链 |
| USB/线束被云台拉扯 | 中 | 高 | 全范围慢速运动 | 应力释放、重新布线、限制角度 |
| 超声暴露未知 | 中 | 高 | 合适频带仪器 | 缩短暴露、扩大距离、限制人员区域 |

## 10. 故障排查顺序

### 完全没有输出

1. 检查 12 V、3.3 V 和公共地。
2. 检查固件是否上电默认静音以及是否收到启动命令。
3. 测 GPIO4，再测 U0、U1～U3，最后测 TC4428。
4. 用接收换能器或示波器确认 40 kHz，不以“听不到”为结论。

### 内置音频正常、实时流异常

1. 用同一 PCM 字节和同一调制模式做串口对照。
2. 查看 buffer、under、over、crc、gap、skip 和 host_drop。
3. 分别只运行音频、只运行视觉，再运行完整系统。
4. 检查采集设备、系统回环 helper 和实际采样率。

### 有声但失真或不定向

1. 回到 `RAW + STANDARD + DSB-AM`。
2. 区分空气自解调与换能器/结构直接可听辐射。
3. 检查 GPIO4 更新抖动和电源纹波。
4. 在相同基波声压下重新比较调制方式。

### 云台行为异常

1. 断开 12 V 超声功率，保留低风险舵机测试。
2. 检查 GPIO5/6、逻辑方向、补偿和软限位。
3. 确认当前显示是指令角度而非反馈。
4. 检查目标 ID、选择状态和相机安装是否移动。

## 11. 对外表述

推荐表述：

> 当前系统使用 120 个 40 kHz 换能器同相组成参量阵，单路调制信号经缓冲器复制到 12 个功率支路。阵面方向由电脑视觉控制的二维机械云台改变。系统支持内置和实时音频，但电子相位转向、定点聚焦、声压标定和硬件急停不属于当前已实现能力。

没有对应证据时，不应声称：

- 已达到某个 dB SPL 或安全暴露等级；
- 已实现人脸识别、身份识别或自动选人；
- 已实现电子聚焦或逐阵元控制；
- 手机读数能够证明 40 kHz 声压；
- 软件停止等于切断 12 V；
- 相对声场 UI 是真实声压测量。

## 12. 现场回退

| 故障 | 回退方式 |
|---|---|
| 声场分析异常 | 关闭 `spatial_field.enabled` |
| GPU 推理异常 | 使用 CPU 或已验证的另一推理后端 |
| 视觉跟踪异常 | 停止追踪，使用 WASD 手动控制 |
| 云台异常 | 断开舵机电源，固定阵面演示 |
| 实时音频异常 | 使用 Flash PCM |
| 串口异常 | 使用固件本地字母命令 |
| BOOST/LOUD 失真或过热 | 回到 RAW + STANDARD + DSB-AM |
| 任意功率异常 | 立即物理断开 12 V |

## 13. 最终检查表

```text
□ Git 提交、配置、依赖锁和固件版本已记录
□ 全量 Python 测试、语法检查和固件编译通过
□ 12 路映射、120 阵元极性和实物标签一致
□ 120 只的 40 kHz R/X 原始数据、12 组配组表和阵面位置已归档
□ 保险丝、总开关、星形地和去耦检查完成
□ 单只、单组、十二组的波形和温升已归档
□ Flash 与实时音频对照完成
□ 云台方向、零点、软限位和线束全范围检查完成
□ 方向图、频响或失真结论有原始数据
□ 演示回退和物理断电流程已演练
□ 未把未来功能或相对模拟写成已测能力
```

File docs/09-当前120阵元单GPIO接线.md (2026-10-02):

# 当前120阵元单GPIO接线

> 版本：v1.2
> 日期：2026-10-02
> 状态：比赛整机施工基线

## 1. 方案边界

- 120 个 `TCT40-16T` 换能器，分成 12 组，每组 10 个并联。
- 12 片 `TC4428AEPA`，编号 `P1`～`P12`，每片驱动一组。
- 4 片 `SN74HC125N`，编号 `U0`～`U3`，把 GPIO4 两级扇出为 12 路。
- 12 路逻辑和功率输出全部同相，不做电子相位转向。
- 波束方向由二维机械云台改变，摄像头和电脑视觉只负责给出云台目标方向。
- 120 只换能器已逐只测量 40 kHz 复阻抗，按容性/感性和并联等效负载配成 12 组。
- 阵面上容性与感性单元交错放置，避免同类单元在局部集中。
- 当前专用烧录工程为 `src/full_size/full_size.ino`；`src/esp32_s3_4x3_min_test_deprecated` 仅保留作历史台架。
- 洞洞板对外引出四个电气网络：`+12V`、`PUBLIC GND`、`+3.3V`、`GPIO4`。

```text
ESP32-S3 GPIO4
    │
    └── U0：1 → 3
          ├── U1：4 路 → P1～P4
          ├── U2：4 路 → P5～P8
          └── U3：4 路 → P9～P12

P1～P12：每片驱动 10 只并联换能器
总计：12 × 10 = 120 只
```

## 2. 对外四根干线

| 网络 | 来源 | 用途 |
|---|---|---|
| `+12V` | 12V/5A 适配器正极 | 12 片 TC4428 功率供电 |
| `PUBLIC GND` | 适配器负极并与 ESP32 GND 相连 | 全系统公共参考地 |
| `+3.3V` | ESP32-S3 开发板 3.3V | 4 片 SN74HC125 供电 |
| `GPIO4` | ESP32-S3 GPIO4 | 40kHz 调制逻辑信号 |

摄像头 USB 线和云台舵机电源/控制线不经过这四根洞洞板干线，应作为独立线束沿云台转轴留出活动余量。

公共地采用星形入口：

```text
12V适配器负极
   ├── 粗线 → 洞洞板 PUBLIC GND
   └── 短线 → ESP32 GND
```

禁止让 12 片 TC4428 的回流电流先经过 ESP32 排针再返回适配器。

## 3. 12V和地的板内分配

```text
+12V入口
   ├── 支路A → P1～P4
   ├── 支路B → P5～P8
   └── 支路C → P9～P12

PUBLIC GND入口
   ├── 逻辑地 → U0～U3及所有10kΩ下拉
   ├── 功率地A → P1～P4
   ├── 功率地B → P5～P8
   └── 功率地C → P9～P12
```

建议线径：

| 位置 | 线径 |
|---|---|
| 12V/GND 外部活动主线 | 18AWG 柔软硅胶线 |
| 洞洞板三条功率支路 | 18～20AWG |
| 支路到单片 TC4428 | 20～22AWG 短线 |
| 3.3V、GPIO4及逻辑线 | 24～26AWG |
| TC4428到10只换能器 | 20～22AWG |

洞洞板细铜箔不能直接充当整机大电流母线，应在背面补焊粗铜线。

## 4. SN74HC125引脚

```text
                 缺口
          ┌──────────────┐
1OE     1 │              │ 14 VCC
1A      2 │              │ 13 4OE
1Y      3 │              │ 12 4A
2OE     4 │              │ 11 4Y
2A      5 │              │ 10 3OE
2Y      6 │              │  9 3A
GND     7 │              │  8 3Y
          └──────────────┘
```

U0～U3共同供电：

```text
pin 14 → +3.3V
pin 7  → 逻辑GND
pin 14与pin 7之间 → 104（100nF）陶瓷电容
```

每片芯片旁各放一个 104，共 4 个；3.3V入口再并联一个 10µF。

## 5. GPIO4和第一级U0

```text
GPIO4
  │
  10Ω / 1/4W
  │
  ├── U0 pin 2
  ├── U0 pin 5
  ├── U0 pin 9
  └── 10kΩ / 1/4W → GND
```

U0前三路启用：

```text
U0 pin 1  → GND
U0 pin 4  → GND
U0 pin 10 → GND
```

U0第四路关闭：

```text
U0 pin 13 → +3.3V
U0 pin 12 → GND
U0 pin 11 → 悬空
```

第一级输出：

```text
U0 pin 3 → U1的pin 2、5、9、12
U0 pin 6 → U2的pin 2、5、9、12
U0 pin 8 → U3的pin 2、5、9、12
```

U1～U3四路全部启用：

```text
pin 1、pin 4、pin 10、pin 13 → GND
```

`OE`为低有效，因此使用中的 `OE`必须接地，不能悬空。

## 6. 12路逻辑输出

| 路 | 缓冲器输出 | 功放 | 负载组 |
|---:|---|---|---|
| 1 | U1 pin 3 | P1 | G01：配组表中的 10 只 |
| 2 | U1 pin 6 | P2 | G02：配组表中的 10 只 |
| 3 | U1 pin 8 | P3 | G03：配组表中的 10 只 |
| 4 | U1 pin 11 | P4 | G04：配组表中的 10 只 |
| 5 | U2 pin 3 | P5 | G05：配组表中的 10 只 |
| 6 | U2 pin 6 | P6 | G06：配组表中的 10 只 |
| 7 | U2 pin 8 | P7 | G07：配组表中的 10 只 |
| 8 | U2 pin 11 | P8 | G08：配组表中的 10 只 |
| 9 | U3 pin 3 | P9 | G09：配组表中的 10 只 |
| 10 | U3 pin 6 | P10 | G10：配组表中的 10 只 |
| 11 | U3 pin 8 | P11 | G11：配组表中的 10 只 |
| 12 | U3 pin 11 | P12 | G12：配组表中的 10 只 |

不再根据 `T001～T120` 的连续编号猜测分组。实际焊接以实测后保存的 `换能器编号 → 组号 → 阵面位置` 对照表为唯一依据。

每路输出到功放输入：

```text
SN74HC125输出Y
    │
   47Ω / 1/4W
    │
    ├── 对应TC4428 pin 2
    ├── 对应TC4428 pin 4
    └── 10kΩ / 1/4W → GND
```

每片 TC4428 的 pin 2 和 pin 4 连接成同一个输入节点，因此每片只需一个 10kΩ下拉。

## 7. 每片TC4428接线

```text
              缺口
         ┌──────────┐
NC     1 │          │ 8 NC
IN_A   2 │          │ 7 OUT_A
GND    3 │          │ 6 VDD
IN_B   4 │          │ 5 OUT_B
         └──────────┘
```

P1～P12全部相同：

```text
pin 1 → 悬空
pin 2 → 47Ω之后的输入节点
pin 3 → 功率GND
pin 4 → 与pin 2连接
pin 5 → 换能器组B端
pin 6 → +12V
pin 7 → 经过4.7Ω后接换能器组A端
pin 8 → 悬空
```

每片TC4428的 pin 6 与 pin 3 之间并联：

- 104（100nF）陶瓷电容一个，必须贴近芯片；
- 10µF、耐压不低于25V电容一个，正极接 pin 6。

## 8. 输出阻尼与10只换能器

```text
TC4428 pin 7
      │
   4.7Ω / 2W
      │
      ├── 该组换能器1标记脚
      ├── 该组换能器2标记脚
      ├── ……
      └── 该组换能器10标记脚

TC4428 pin 5
      │
      ├── 该组换能器1另一脚
      ├── 该组换能器2另一脚
      ├── ……
      └── 该组换能器10另一脚
```

- 每组一个4.7Ω，共12个；推荐2W低电感金属氧化膜或功率厚膜电阻。
- 4.7Ω是输出限流/阻尼，不是阻抗匹配。
- 初次上电保留4.7Ω；确认过冲、振铃和温升安全后，才可对比2.2Ω。
- 不建议初次测试直接用0Ω。
- 换能器两端都是浮动差分输出，任何一端都不能接GND。
- P1～P12的功率输出禁止互相并联。
- 每组A/B两根线靠近布置或适度绞合，TC4428尽量靠近负载。

## 9. 40 kHz 复阻抗配组

每只换能器在相同夹具、激励幅值和 40 kHz 测量条件下记录：

```text
Z_i = R_i + jX_i
```

- `X_i < 0`：该测量点呈容性；
- `X_i > 0`：该测量点呈感性；
- `X_i ≈ 0`：该测量点接近纯阻性。

每组 10 只是并联连接，因此必须先转换为导纳再求和：

```text
Y_i     = 1 / Z_i
Y_group = Σ Y_i = G_group + jB_group
Z_group = 1 / Y_group
```

不能直接计算 `ΣZ_i`。配组时同时考虑三个目标：

1. 每组混合容性和感性单元，使 `|B_group|` 或 `|Im(Z_group)|` 尽量小；
2. 使 12 组的 `|Z_group|`、实部和预计电流尽量接近，避免个别 TC4428 负载过重；
3. 在阵面上交错分布容性与感性单元，同时保持所有单元的声学极性一致。

这一操作是基于单元离散差异的负载配组，不等于已实现了带宽内的理想共轭匹配。语音调制后仍包含 40 kHz 两侧的边带，如需评估全带效果，应再测 38～42 kHz 的组阻抗曲线。

建议的原始记录字段为：

| 换能器编号 | `R @ 40 kHz` | `X @ 40 kHz` | 容/感性 | 组号 | 阵面位置 |
|---|---:|---:|---|---|---|
| 以实测表为准 |  |  |  | G01～G12 |  |

任何一只换能器更换、重新焊接或跨组移动后，都必须更新对照表并重新计算受影响组的 `Z_group`。

## 10. 电源入口去耦

12V总入口：

```text
+12V与GND之间
├── 1000µF / ≥25V
└── 104
```

三条功率支路起点各安装：

```text
+12V与对应功率地之间
├── 470µF / ≥25V
└── 104
```

这些入口电容不能代替每片TC4428旁边的104和10µF。

## 11. 元件数量

### 电阻

| 型号 | 数量 | 用途 |
|---|---:|---|
| 10Ω、1/4W | 1 | GPIO4进入U0前串联 |
| 10kΩ、1/4W | 13 | GPIO4下拉1个，12路功放输入下拉 |
| 47Ω、1/4W | 12 | U1～U3输出到TC4428输入 |
| 4.7Ω、2W | 12 | 12组换能器输出阻尼 |

### 电容

| 型号 | 最低数量 | 推荐数量 | 用途 |
|---|---:|---:|---|
| 104陶瓷 | 16 | 20 | 4片SN74HC125、12片TC4428及电源入口 |
| 10µF、≥25V | 12 | 13 | 12片TC4428及3.3V入口 |
| 470µF、≥25V | 3 | 3 | 三条12V支路 |
| 1000µF、≥25V | 1 | 1 | 12V总入口 |

## 12. 上电与测量顺序

1. 先焊电源母线，断电检查12V与GND无短路。
2. 焊U0～U3及其去耦，只接3.3V，确认12路逻辑输出同相。
3. 焊12片TC4428的输入网络和近端去耦，暂不接换能器。
4. 每次只插一片TC4428，确认 pin 5、pin 7 对地均为约0～12V且互补。
5. 示波器差分测量使用两探头都以公共地为参考，再做 `CH1-CH2`；禁止把地夹接到pin 5或pin 7。
6. 核对实测配组表，确认每只换能器的组号、位置和极性标记。
7. 先接单只换能器，再扩到该组 10 只，监测波形、电流、TC4428 和 4.7 Ω温升。
8. 单组通过后逐组增加，最后才接满 120 只。
9. 完整阵列首次运行把软件调制度/音量设低，再逐步增加。

推荐上电：

```text
先接3.3V逻辑并确认GPIO稳定 → 再接12V功率
```

推荐断电：

```text
先断12V功率 → 再断3.3V逻辑
```

串口停止播放不等于12V已断电。改线、插拔芯片或连接示波器前必须物理断开12V电源。

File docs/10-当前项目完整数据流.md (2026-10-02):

# 当前项目完整数据流

> 版本：v1.5
> 日期：2026-10-02
> 适用范围：`src/full_size` 固件与当前 120 阵元单 GPIO 整机  
> 目标：让具备 Arduino、ESP32 或嵌入式基础的开发者在 10 分钟内理解当前系统

> 2026-09-10更新：视觉跟踪、二维舵机、实时麦克风串流和超声调制已由同一桌面程序及二进制串口贯通。本文保留Flash播放细节；视觉控制见 [11-视觉云台跟踪系统.md](11-视觉云台跟踪系统.md)，实时链路见 [12-实时麦克风与音频流协议.md](12-实时麦克风与音频流协议.md)。

## 1. 先明确当前版本

当前已经建立专用的 120 阵元固件：

- `src/full_size` 只配置一个 LEDC 输出通道和 `GPIO4`；
- GPIO4 由缓冲器扇出为 12 路同相信号，每路驱动 10 只经 40 kHz 复阻抗实测配组的换能器；
- 旧固件中的 GPIO5～GPIO7、四路更新循环和 `1～4` 单列命令已经删除；
- 当前没有电子相位转向或逐阵元控制，波束方向由二维机械云台改变；
- `src/esp32_s3_4x3_min_test_deprecated` 保留为历史 12 阵元台架，不再作为 120 阵元烧录入口。

因此，理解当前行为时按以下优先级判断：

1. 实际固件行为以 `src/full_size` 源码为准；
2. 当前整机接线以 [09-当前120阵元单GPIO接线.md](09-当前120阵元单GPIO接线.md) 为准；
3. [08-当前12阵元原型.md](08-当前12阵元原型.md) 和归档固件 README 只用于解释历史 4×3 台架；
4. 文档 01～07 已按当前 120 阵元机械转向基线重写；任何未来电子相控研究必须单独标记，不能覆盖当前接线。

## 2. 总数据流

```text
离线 PCM WAV
    │  wav_to_audio_header.py
    ▼
audio_data.h：8 kHz、8-bit、单声道 PCM，存入 Flash
    │
    │                    串口命令
    │                       │
    │                       ▼
    │              controlTask → 命令队列
    │                               │
    │          GPTimer ISR ─────────┤ 通知
    │          8 kHz节拍            ▼
    └──────────────────────→ playbackTask
                                    │
                                    ▼
                         ModulationEngine
                     固定载波 / 纯音 / PCM音频
                                    │
                                    ▼
                            duty + sampleRate
                                    │
                                    ▼
                 LEDC Timer 0 / Channel 0：默认40 kHz、10-bit
                                    │
                                  GPIO4
                                    │
                                    ▼
                       SN74HC125：1路扇出12路
                                    │
                                    ▼
                          12片 TC4428A
                         12 V互补差分输出
                                    │
                                    ▼
                 12组×10只并联换能器
               40 kHz复阻抗配组，容/感性交错
                                    │
                                    ▼
                          120阵元同相超声波束
                                    │
                                    ▼
                         空气非线性产生可听声
```

串口现在复用实时音频、云台和控制消息。电脑端只有一个 `SerialDeviceLink` 拥有COM口；Flash播放仍可脱离电脑工作。

电脑参与时的完整闭环为：

```text
摄像头 → YOLO/ByteTrack → 目标角偏差 → PI与运动限制 → 云台角度 ─┐
                                                                ├→ 共享串口 → ESP32
麦克风/立体声混音/进程回环 → 滤波/压缩/限幅 → 8 kHz PCM_U8 → 音频帧 ─┘ ├→ 二维舵机
                                                                            └→ 调制/GPIO4 → 120阵元
```

## 3. 音频进入固件之前

转换工具位于 `utils/wav_to_audio_header.py`，处理过程为：

```text
未压缩PCM WAV
→ 多声道平均为单声道
→ 线性重采样到8 kHz
→ 去直流
→ 峰值归一化到约90%
→ 首尾各10 ms淡入淡出
→ 8位无符号PCM
→ 生成src/full_size/src/data/audio_data.h
```

生成的数组使用 `PROGMEM`，随固件烧入 Flash。当前头文件配置为：

| 项目 | 当前值 |
|---|---:|
| 采样率 | 8000 Hz |
| 样本格式 | 8-bit unsigned PCM |
| 样本数 | 36240 |
| 时长 | 4.53 s |
| `kAudioIsDemo` | `false` |

Flash播放时每个采样节拍通过 `pgm_read_byte()` 读取一个字节。实时模式则从2048样本的内部RAM环形缓冲读取；两种音源共用后续调制和LEDC链。更换内置音频仍需重新生成头文件并烧录。

## 4. 上电与软件任务

Arduino 入口 `src/full_size/full_size.ino` 依次执行：

1. 启动 460800 波特率串口；
2. 初始化 `UltrasonicDriver`；
3. 初始化 `UltrasonicApp`；
4. Arduino `loop()` 只休眠，业务由 FreeRTOS 任务处理。

驱动初始化内容：

- GPIO4 先置低，避免启动脉冲；
- LEDC Timer 0 使用 80 MHz APB 时钟；
- 默认载波 40 kHz，可在 38～42 kHz 间以 100 Hz 步进调整；
- 分辨率为 10-bit，即每周期 1024 counts；
- 最大有效占空比限制为 512 counts，即 50%；
- 上电默认占空比为 0，输出关闭。

应用层创建两个任务：

| 任务 | 优先级 | 职责 |
|---|---:|---|
| `controlTask` | 2 | 解析串口字符并把命令放入队列 |
| `playbackTask` | 8 | 独占调制器、GPTimer状态和LEDC驱动 |

命令队列长度为 8。播放任务固定到注册 GPTimer 中断的同一核心，以减少跨核通知抖动。

## 5. 控制命令流

```text
串口字符
→ controlTask解析
→ Command {type, value}
→ FreeRTOS命令队列
→ 通知playbackTask
→ 启停输出或改变配置
```

| 命令 | 行为 |
|---|---|
| `0`+回车 | 停止调制定时器并把 GPIO4 LEDC 占空比置 0 |
| `A` | 完整阵列输出当前载波、50%占空比 |
| `T` | 完整阵列启动 1 kHz 连续正弦包络 |
| `20`～`3000`+回车 | 启动指定频率的连续正弦包络 |
| `P` / `L` | Flash PCM 播放一次 / 循环播放 |
| `D` / `S` | 下次音频使用 DSB-AM / SRAM |
| `R` / `E` | 下次音频使用原始 PCM / 响度增强 PCM |
| `N` / `B` | 下次纯音或音频使用 STANDARD / BOOST 包络 |
| `-`、`[` / `+`、`]` | 载波降低 / 升高 100 Hz |
| `C` / `F` | 恢复 40 kHz / 打印实际载波 |
| `H` / `?` | 打印帮助 |

`D/S/R/E/N/B`只选择后续播放参数，不改变已经开始的纯音或音频。所有发射命令最终只更新 GPIO4，外部 SN74HC125 再把它复制到 12 路功率支路。

## 6. 三种发射路径

### 6.1 固定载波

`A`直接写单个 LEDC 通道，不启动 8 kHz采样定时器：

```text
duty = 512
hpoint = (1024 - duty) / 2 = 256
```

结果是当前载波频率下、50%占空比、脉冲中心固定的连续方波。

### 6.2 正弦包络测试

纯音使用 8 kHz 更新率、32位相位累加器和256点正弦查找表：

```text
目标频率 → 相位累加器 → 正弦表索引 → 包络表 → duty
```

| 模式 | 包络 |
|---|---|
| STANDARD | `E = 0.55 + 0.40·sin(ωt)` |
| BOOST | `E = 0.50 + 0.48·sin(ωt)` |

支持 20～3000 Hz，不要求目标频率整除 8 kHz。

### 6.3 Flash PCM音频

```text
Flash中的uint8_t样本
→ RAW或LOUD处理
→ 主音量渐变（0% 时 PWM 占空比为 0）
→ DSB-AM或SRAM查找表
→ ModulationFrame
→ GPIO4 LEDC duty更新
```

LOUD 模式包含约 `2/128` 的噪声门和约 6 倍的小信号增益，并在接近满幅时软压缩。相关变换在初始化时预先生成256项查找表，播放期间不逐样本执行浮点压缩计算。

调制公式为：

```text
s = (sample - 128) / 128

DSB-AM: E = b + d·s
SRAM:   E = sqrt((b+d)·(b+d·s))
```

| 驱动模式 | `b` | `d` | DSB理论包络范围 |
|---|---:|---:|---:|
| STANDARD | 0.45 | 0.40 | 0.05～0.85 |
| BOOST | 0.50 | 0.48 | 0.02～0.98 |

这里的 SRAM 指 Square-Root Amplitude Modulation，不是 ESP32 片上存储器。

## 7. 包络如何变成40 kHz PWM

40 kHz 方波基波幅值近似与 `sin(πD)` 成正比，因此调制层使用反正弦映射：

```text
D = asin(E) / π
duty = round(D × 1024)
```

结果限制在 `1～512` counts。驱动层再计算：

```text
hpoint = (1024 - duty) / 2
```

这样改变占空比时，高电平脉冲仍围绕计数周期中心排列，减少由单边沿移动导致的附加相位变化。当前只有一个软件输出通道；12 路同步复制由外部缓冲器完成，不存在软件逐通道更新时间差，也没有通道相位表。

## 8. 8 kHz调度与积压处理

GPTimer 分辨率为 40 MHz。8 kHz采样对应：

```text
40,000,000 / 8,000 = 5,000个计数 = 125 µs
```

默认 40 kHz载波周期为25 µs，因此一个音频样本理论上覆盖5个载波周期。

GPTimer ISR不读取音频、不写LEDC，也不打印串口，只执行：

1. `pendingTimerTicks++`；
2. 通知 `playbackTask`。

播放任务醒来后读取积压节拍。若积压多于1个，就跳过已经过期的PCM样本或纯音相位，只渲染最新帧，从而保持音调和总时长，而不是把整段音频放慢。发生跳帧后，停止时会打印 `TIMING WARNING`。

当前调制不是载波同步 DMA：8 kHz更新由任务执行，LEDC更新时刻没有与40 kHz周期边界硬件锁存。最终时序和毛刺仍需示波器或逻辑分析仪验证。

## 9. GPIO4到120阵元

```text
GPIO4
→ 10Ω串联、10kΩ下拉
→ U0前三路缓冲
→ U1/U2/U3各四路缓冲
→ 12路同相3.3 V逻辑
→ 每路47Ω串联、10kΩ下拉
→ 对应TC4428A的IN_A与IN_B
```

SN74HC125只负责逻辑扇出。换能器能量来自12 V电源，而不是GPIO或3.3 V逻辑电源。

每片TC4428A的两个输入接在同一逻辑节点，一路反相、一路同相，形成互补输出：

```text
TC4428 pin 7 OUT_A ──4.7Ω──┐
                           ├─ 10只TCT40-16T并联
TC4428 pin 5 OUT_B ─────────┘
```

12 V供电时，两端分别在约0～12 V间互补切换，换能器组得到接近24 Vpp的浮动差分方波。12组接收同一时间序列并同相发射，形成固定轴向超声波束；空气非线性再从超声包络中产生可听成分。

每个 10 只负载组不按顺序编号随机组成。装配前对 120 只换能器逐只测量 40 kHz 处 `Z_i = R_i + jX_i`，并按下式计算并联等效负载：

```text
Y_group = Σ(1 / Z_i)
Z_group = 1 / Y_group
```

分组时将容性与感性单元混合，使各组等效虚部尽量小，并平衡 12 路的阻抗幅值和电流。阵面上同时交错放置容性/感性单元。该匹配是实物负载的配组步骤，不改变 GPIO4、PWM 或串口数据流。

## 10. 电源、视觉与安全边界

数据流和能量流必须分开理解：

```text
GPIO4数据 → SN74HC125 → TC4428输入
3.3 V能量 → SN74HC125
12 V能量 → 12片TC4428 → 120只换能器
PUBLIC GND → ESP32、缓冲器和功率驱动的公共参考
```

摄像头和PC视觉负责计算目标方向，ESP32固件接收云台角度并驱动二维舵机，同时输出超声调制。YOLO、目标锁定和闭环PI仍在电脑端；固件没有摄像头输入、逐通道相位或独立的视觉跟踪逻辑。

串口`0`只停止40 kHz切换，不会切断12 V。TC4428在静态逻辑输入下仍可能保持一个输出高、另一个输出低。改线、插拔芯片或连接示波器前必须物理断开12 V。

## 11. 当前已知边界

- 120 阵元固件已经收敛为 GPIO4 单输出，但仍未加入独立硬件 OE/12 V 断电控制；
- 已支持麦克风、Realtek 立体声混音与不受物理扬声器音量/静音影响的 Windows 进程回环；尚未实现ESP32本地I²S麦克风、USB Audio设备类或网络音频；
- 进程回环在数字静音持续 1 s 后停止实时流和 PWM，检测到内容后自动重启与预缓冲；
- 没有电子转向、聚焦、相位校准或逐组增益控制；
- 当前配组依据 40 kHz 单点复阻抗；对调制边带的完整匹配效果还需用 38～42 kHz 支路阻抗扫频验证；
- 实时音频有内部RAM环形缓冲，但Flash和实时流仍由任务逐样本更新，没有载波同步DMA；
- PWM占空比调制可能引入低频平均分量和非定向机械可听泄漏；
- GPIO4到12路缓冲输出、12片TC4428传播延时和实际同相程度仍需要测量；
- 手机麦克风和分贝App不能用于校准40 kHz声压或判断超声暴露安全。

## 12. 代码入口速查

| 文件 | 职责 |
|---|---|
| `src/full_size/full_size.ino` | Arduino启动入口 |
| `src/full_size/src/app/ultrasonic_app.cpp` | 串口、命令队列、任务和GPTimer调度 |
| `src/full_size/src/driver/ultrasonic_driver.cpp` | GPIO4、单LEDC载波、占空比和频率 |
| `src/full_size/src/driver/gimbal_controller.cpp` | 二维舵机角度与LEDC输出 |
| `src/full_size/src/modulation/modulation_engine.cpp` | 在关闭、纯音和PCM音频模式间切换 |
| `src/full_size/src/modulation/audio_modulator.cpp` | LOUD处理、主音量和音频调制选择 |
| `src/full_size/src/modulation/envelope_modulator.cpp` | 连续正弦包络测试 |
| `src/full_size/src/modulation/dsb_am_modulator.cpp` | DSB-AM查找表 |
| `src/full_size/src/modulation/sram_modulator.cpp` | 平方根幅度调制查找表 |
| `src/full_size/src/modulation/modulation_math.h` | 包络到PWM占空比的反正弦映射 |
| `src/full_size/src/data/audio_data.h` | 当前烧入Flash的PCM样本 |
| `src/vision_gimbal/infrastructure/serial_device_link.py` | 复用云台、音频和状态帧的唯一COM口所有者 |
| `src/vision_gimbal/infrastructure/wasapi_process_loopback.py` | 管理不受物理扬声器静音影响的 Windows 进程回环 |
| `native/wasapi_process_loopback/main.cpp` | 原生 WASAPI 进程回环与10 ms静音时钟 |
| `src/vision_gimbal/ui/audio_panel.py` | 三种实时音源切换、启停、主音量与RAW/LOUD、BOOST、DSB-AM/SRAM控制 |

完整链路可以概括为：**控制命令选择信号源和调制参数，GPTimer以8 kHz推动调制帧，LEDC把帧转换为40 kHz可变占空比波形，GPIO4经缓冲器复制成12路同相信号，TC4428将其转换为12 V差分功率输出，最终同时驱动12组经40 kHz复阻抗配组的120只换能器。**

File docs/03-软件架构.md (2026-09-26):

# 03 · 当前软件架构、接口与运行边界

> 版本：v2.1
> 日期：2026-09-26
> 适用范围：`src/vision_gimbal`、`src/full_size` 和协议 V1

当前软件由 Windows 桌面端和 ESP32-S3 固件组成。视觉识别、用户交互和音频预处理在电脑上运行；载波、调制、缓冲、舵机 PWM 和故障静音在 ESP32 上运行。

## 1. 软件全景

```text
┌──────────────── Windows 桌面端 ────────────────┐
│ 摄像头 → YOLO/ByteTrack → Kalman → 目标锁定    │
│                         → PI → 运动限制          │
│ 麦克风/电脑声音 → DSP → PCM_U8                 │
│ UI 意图 ────────────────┐                       │
│                          └→ SerialDeviceLink     │
└──────────────────────────────┬───────────────────┘
                               │ COBS + CRC16
┌──────────────────────────────▼───────────────────┐
│ ESP32：协议服务器、音频环形缓冲、8 kHz GPTimer  │
│        调制查表、GPIO4 LEDC、GPIO5/6 舵机 PWM   │
└──────────────────────────────┬───────────────────┘
                               │
                   云台 + 120 阵元超声发射链
```

电脑端只有一个对象拥有 COM 口。音频服务和云台控制都向 `SerialDeviceLink` 发布消息，不能各自打开串口。

## 2. 桌面端目录和依赖方向

```text
src/vision_gimbal/
├─ domain/          不依赖 UI 或硬件的数据合同
├─ ports/           摄像头、跟踪器、音源和设备链接口
├─ vision/          YOLO、ByteTrack、去重和逐 ID Kalman
├─ control/         目标锁定、近距离瞄准、PI、手动控制和限位
├─ audio/           滤波、重采样、电平、压缩、量化、录音和频谱
├─ spatial/         可选深度和相对自由场模型
├─ protocol/        Python 协议帧、CRC 和消息结构
├─ application/     生命周期、会话和服务编排
├─ infrastructure/  OpenCV、PortAudio、WASAPI 和串口适配器
├─ ui/              PySide6 控件、绘制和工作线程
├─ bootstrap.py     唯一组合根
└─ __main__.py      正式桌面启动入口
```

依赖方向为 `UI/infrastructure → application → control/vision/audio → domain/ports`。领域对象不应导入 PySide6、OpenCV 串口实现或 ESP32 细节。

## 3. 视觉流水线

```text
OpenCVCamera
→ YOLOByteTrackPeopleTracker（只检测 person 类）
→ suppress_duplicate_people
→ PerTrackKalmanSmoother
→ VisionSnapshot
```

每个 `TrackedPerson` 包含 `track_id`、边界框、检测中心、控制瞄准点、置信度和是否为真实观测。短期丢帧可以由 Kalman 预测补充，但预测有最大帧数和目标释放超时。

当前系统只做人检测和轨迹 ID，不做人脸识别或身份识别。

## 4. 目标会话和云台控制

控制链刻意要求用户显式选择目标：

1. 用户点击人物框，形成选中目标；
2. 用户点击“开始追踪”，选中目标才成为活动目标；
3. 自动追踪期间点击其他人只更新待切换目标；
4. 再次点击“开始追踪”后才切换；
5. 活动目标超时后停止自动追踪，不自动跳到其他人。

自动控制路径：

```text
TargetObservation
→ CloseRangeAimPolicy
→ CameraProjection
→ pan/tilt AxisVelocityPid
→ MotionRequest
→ CommandArbiter
→ GimbalMotionLimiter
→ GimbalSetpoint
→ DeviceGimbalSink
→ SerialDeviceLink
```

手动 `W/A/S/D` 只在停止自动追踪时生效。自动和手动请求统一经过速度、加速度和角度限制。

UI 显示的是最后下发的指令角度，不是编码器反馈；当前云台没有位置回读。

## 5. 音频流水线

音源包括：

- 麦克风；
- PortAudio 立体声混音；
- Windows WASAPI 进程回环；
- 固件内置 Flash PCM。

电脑端实时音频路径：

```text
48 kHz float32 / 10 ms
→ 单声道
→ 250 Hz 高通
→ 3 kHz 抗混叠低通
→ 有状态重采样到 8 kHz
→ 电平控制、压缩和 -1.5 dBFS 限幅
→ PCM_U8
→ 160 样本 / 20 ms 数据包
```

实时音频、状态帧和云台命令共享同一协议会话。进程回环持续数字静音 1 秒后，音频服务停止 ESP32 流和 PWM；检测到新内容后重新建立流并预缓冲。

主音量由桌面端滑块经可靠 `SET_VOLUME` 命令发送到固件。固件在 RAW/LOUD 之后、调制之前平滑衰减音频，实时流与内置 Flash PCM 共用；0% 使音频 PWM 关闭。桌面端从 `HELLO_ACK` 能力位确认固件支持后，先同步音量再启动流。

完整协议字段见 [12-实时麦克风与音频流协议.md](12-实时麦克风与音频流协议.md)。

## 6. 可选深度与相对声场

`SpatialFieldService` 是默认关闭的显示支路：

- 使用单槽队列，只保留最新帧；
- 不参与目标选择、PI、串口或音频；
- 需要 `spatial` 可选依赖和 OpenVINO 模型；
- 输出是相对自由场可视化，不是经过校准的 dB SPL；
- 推理持续超时会停用该显示支路，而不影响主控制链。

## 7. ESP32 固件结构

```text
src/full_size/
├─ full_size.ino
└─ src/
   ├─ app/         命令、任务、状态机和 GPTimer
   ├─ audio/       Flash 与实时环形缓冲音源
   ├─ driver/      GPIO4 超声和 GPIO5/6 舵机
   ├─ modulation/  DSB-AM、SRAM、包络和查表
   ├─ protocol/    COBS、CRC16 和协议服务器
   └─ data/        当前内置 PCM
```

固件创建控制任务和高优先级播放任务。GPTimer ISR 只累计节拍并通知播放任务，不在中断中读取音频、打印串口或执行完整调制。

当前输出只有一个超声 LEDC 通道。12 路同步由外部 SN74HC125 复制，不存在软件相位数组或逐路更新循环。

## 8. 协议 V1

每个原始帧包含：

```text
magic/version/type/flags/payload_length
session_id/sequence/sample_index/payload/crc16
```

原始帧经过 COBS 编码，并以前后 `0x00` 定界。可靠控制命令要求 ACK；音频数据不 ACK、不重传，损坏或过期音频直接丢弃。

关键消息：`HELLO`、`STREAM_START`、`AUDIO_DATA`、`STREAM_STOP`、`SET_MUTE`、`SET_VOLUME`、`GIMBAL_SETPOINT`、`STATUS` 和 `COMMAND_ACK`。

固件仍保留字母命令和文本 `(pan,tilt)` 作为台架操作接口，但正式桌面端使用二进制协议。

## 9. 配置合同

唯一当前项目配置是 `configs/vision_gimbal.toml`。相对路径以配置文件所在目录解析。配置加载器拒绝未知字段，以避免拼写错误静默生效。

关键边界：

- Python 3.10～3.12；推荐 3.11；
- 串口默认 460800 baud；
- 实时音频固定 8 kHz、单声道、PCM_U8；
- 固件云台协议范围为两轴 -90°～90°；
- `cuda` 与 `xpu` 依赖互斥；
- `spatial_field.enabled` 默认 `false`。

## 10. 生命周期与错误隔离

桌面程序启动顺序：设备链 → 视觉 → 控制 → 音频。关闭顺序首先停止音频采集和传输，再关闭控制、视觉和共享串口。

以下支路不得阻塞核心闭环：

- 频谱分析队列满时丢弃旧可视化块；
- 声场分析队列满时替换旧帧；
- 串口重连在后台进行；
- 迟到的旧音源回调不得进入新的音频会话。

## 11. 正式入口和测试

桌面程序：

```powershell
$env:PYTHONPATH = ".\src"
uv run python -m vision_gimbal --camera-index 0 --serial-port COM5
```

测试：

```powershell
uv sync --locked --python 3.11
uv run python -m pytest -q
uv run python -m compileall -q src utils
```

pytest 只收集 `tests/`。`src/cv_test_deprecated` 和 `src/esp32_s3_4x3_min_test_deprecated` 是历史实现，不是正式模块或测试入口。

## 12. 当前未实现

- 电子相位转向和定点聚焦；
- 阵元或功率支路的独立增益/相位校准；
- ESP32 本地 I²S 麦克风、USB Audio 或网络音频；
- 舵机角度编码器反馈；
- 独立硬件 OE、12 V 急停或软件可控功率断开；
- 经过声压标定的三维声场模型。

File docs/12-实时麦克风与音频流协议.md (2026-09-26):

# 实时音源与音频流协议

> 版本：v1.5
> 日期：2026-09-26
> 电脑端：`src/vision_gimbal` 与 `utils/mic_stream_cli.py`  
> 固件端：`src/full_size`  
> 默认物理链路：460800 baud、8N1 串口

## 1. 数据流

```text
电脑麦克风 ──────┐
立体声混音 ──────┤→ 48 kHz float32 / 10 ms
WASAPI进程回环 ──┘   不受物理扬声器音量/静音影响
→ 单声道
→ 250 Hz高通
→ 3 kHz抗混叠低通
→ 有状态重采样到8 kHz
→ 慢速电平控制、压缩和限幅
→ 可选PCM16 WAV监听录音抽头
→ PCM_U8，静音值128
→ 160样本/20 ms
→ COBS + CRC16二进制帧
→ 唯一SerialDeviceLink
→ ESP32协议服务器
→ 2048样本内部RAM环形缓冲
→ 960样本/120 ms预缓冲
→ 8 kHz GPTimer
→ UI选择的 RAW/LOUD → 主音量渐变 → DSB-AM/SRAM + STANDARD/BOOST
→ LEDC 40 kHz可变占空比
→ GPIO4、SN74HC125、TC4428A和120阵元
```

电脑只传可听基带PCM。40 kHz载波、调制查表、占空比映射和故障静音保留在ESP32。

## 2. 电脑端配置

音频控制面板默认启用，但采集和传输不会自动开始。配置 `configs/vision_gimbal.toml`：

```toml
[serial]
port = "COM5"
baudrate = 460800

[audio]
enabled = true
auto_start = false

[audio.capture]
source = "system_loopback"
device = ""
channels = 1
stereo_mix_device = "立体声混音"
stereo_mix_channels = 2
process_loopback_helper = ""
sample_rate = 48000

[audio.activity_gate]
enabled = true
system_loopback_only = true
silence_threshold_dbfs = -60.0
resume_threshold_dbfs = -50.0
release_ms = 1000

[audio.stream]
processing = "loud"
boost = true
modulation = "dsb_am"

[audio.volume]
default_percent = 50

[audio.recording]
enabled = false
path = "../output/audio_recordings/post_limiter_{timestamp}.wav"
```

录音抽头位于压缩和-1.5 dBFS限幅之后、PCM_U8量化之前，输出为单声道8 kHz、16-bit PCM WAV。`{timestamp}`会替换为启动录音的本地时间；相对路径以配置文件目录为基准。录音只在音频流处于发送状态时写入，停止流或退出程序会正常封口WAV。

桌面程序启动后，`ApplicationRuntime`先打开共享设备链路，再启动视觉、云台控制和音频服务。默认音源为“电脑声音（静音无关回环）”；它使用 Windows 进程回环捕获除本程序及子进程外的系统音频。物理扬声器可以静音，捕获音量和阵列输出不会随之降低。

传输中改变音源会自动静音、清空旧数据并重启流。进程回环连续静音 1 s 后会停止 ESP32 音频流和 PWM；检测到新内容后重新预缓冲并恢复。这与物理扬声器的静音状态无关。helper 异常退出或连续 1 s 没有输出 PCM 块时，桌面端按 250 ms～5 s 的退避间隔自动重建采集。

若只测试麦克风链路：

```powershell
uv run python .\utils\mic_stream_cli.py --serial-port COM5
```

只测试立体声混音链路：

```powershell
uv run python .\utils\mic_stream_cli.py --serial-port COM5 --source stereo_mix
```

测试不受物理扬声器静音影响的进程回环：

```powershell
uv run python .\utils\mic_stream_cli.py --serial-port COM5 --source system_loopback
```

首次使用会调用 `utils/build_wasapi_process_loopback.ps1` 自动编译原生辅助程序，需要 `g++` 在 `PATH` 中。也可先手动执行：

```powershell
.\utils\build_wasapi_process_loopback.ps1
```

`stereo_mix_device`使用设备名查询而不是数字索引，避免声卡插拔后索引变化。可用 `uv run python -m sounddevice` 查看实际名称。当前 Realtek 驱动下默认名称为“立体声混音”。

也可以只对本次命令启用录音并覆盖配置路径：

```powershell
uv run python .\utils\mic_stream_cli.py --serial-port COM5 --record-output .\output\processed.wav
```

按 `Ctrl+C` 时，工具先发送静音和停止流，再关闭串口。程序静音不能代替12 V物理断电。

## 3. 预处理参数

| 阶段 | 当前配置 | 说明 |
|---|---:|---|
| 采集 | 48 kHz、float32、10 ms | 进程回环固定48 kHz；PortAudio音源可配置44.1 kHz |
| 声道 | 平均为单声道 | 可在后续增加左/右声道选择 |
| 高通 | 250 Hz、二阶Butterworth | 去直流、震动和不可用低频 |
| 实测EQ | 关闭 | 不自动使用理论逆f²补偿 |
| 低通 | 3 kHz通带、4 kHz阻带 | Kaiser窗FIR，重采样前抗混叠 |
| 重采样 | 8 kHz | 保存滤波和分数相位状态 |
| 电平 | -8 dBFS目标、最大+30 dB | 高响度配置；静音时冻结增益 |
| 压缩 | -12 dBFS、3:1 | 10 ms attack、120 ms release |
| 限幅 | -1.5 dBFS | 量化前最终保护 |
| 量化 | unsigned 8-bit | `round(128+128*x)`并限幅 |

电脑根据ESP32上报的缓冲水位，以不超过±500 ppm的微量比率修正补偿两端音频时钟漂移。

## 4. 线上帧

原始帧使用小端字段：

| 偏移 | 长度 | 字段 |
|---:|---:|---|
| 0 | 2 | ASCII `UA` |
| 2 | 1 | 协议版本，固定1 |
| 3 | 1 | 消息类型 |
| 4 | 2 | flags |
| 6 | 2 | payload长度，最大512 |
| 8 | 4 | session ID |
| 12 | 4 | sequence |
| 16 | 4 | audio sample index |
| 20 | N | payload |
| 20+N | 2 | CRC-16/CCITT-FALSE |

CRC参数为 `poly=0x1021`、`init=0xFFFF`、`xorout=0`。线上编码为：

```text
0x00 + COBS(header + payload + crc16) + 0x00
```

前导零用于从ESP32启动日志或旧文本协议中重新建立边界；连续零为空帧，直接忽略。

### 4.1 flags

| bit | 名称 |
|---:|---|
| 0 | ACK_REQUIRED |
| 1 | IS_ACK |
| 2 | ERROR |
| 3 | END_OF_STREAM |

### 4.2 消息类型

| 值 | 方向 | 名称 |
|---:|---|---|
| `0x01` | PC→ESP | HELLO |
| `0x02` | PC→ESP | STREAM_START |
| `0x03` | PC→ESP | AUDIO_DATA |
| `0x04` | PC→ESP | STREAM_STOP |
| `0x05` | PC→ESP | SET_MUTE |
| `0x06` | PC→ESP | GIMBAL_SETPOINT |
| `0x07` | PC→ESP | PING |
| `0x08` | PC→ESP | SET_VOLUME |
| `0x81` | ESP→PC | HELLO_ACK |
| `0x82` | ESP→PC | COMMAND_ACK |
| `0x83` | ESP→PC | STATUS |
| `0x84` | ESP→PC | LOG |
| `0x85` | ESP→PC | ERROR |
| `0x87` | ESP→PC | PONG |

## 5. STREAM_START

16字节payload：

| 偏移 | 类型 | 字段 | V1值 |
|---:|---|---|---:|
| 0 | u32 | sample rate | 8000 |
| 4 | u16 | packet samples | 160 |
| 6 | u16 | prebuffer samples | 960 |
| 8 | u8 | sample format | 1=PCM_U8 |
| 9 | u8 | channels | 1 |
| 10 | u8 | modulation | 0=DSB、1=SRAM |
| 11 | u8 | processing | 0=RAW、1=LOUD |
| 12 | u8 | drive | 0=STANDARD、1=BOOST |
| 13 | u8 | underflow policy | 1 |
| 14 | u16 | data timeout ms | 500 |

桌面UI可请求 `RAW/LOUD + DSB-AM/SRAM + STANDARD/BOOST` 的任意组合；当前整机配置默认为 `LOUD + DSB-AM + BOOST`。运行中切换会先停止旧流，再使用新参数发送 `STREAM_START`。只有收到与当前启动请求版本匹配的成功 `COMMAND_ACK` 后，链路才发送已排队的AUDIO_DATA。

电脑端同一时刻只等待一条可靠控制命令的ACK，避免固件单条ACK缓存被后续命令覆盖而使重试重复执行。音频帧保持不要求ACK。

`HELLO_ACK` 的能力位 bit 2 表示固件支持连续主音量。桌面端先确认该位，再发送 `SET_VOLUME`，收到 ACK 后才发送 `STREAM_START`；重连时重发期望音量。缺少该位的旧固件会使桌面端音频启动按钮禁用，避免默认音量设定未生效。`SET_VOLUME` payload 为 2 字节小端无符号整数 `volume_permille`，范围 `0..1000`；0 为关闭音频 PWM，1000 为原有音频幅度。固件对当前增益做约 40 ms 渐变，实时流和内置 Flash PCM 共用这一控制。

## 6. 音频和状态

`AUDIO_DATA` payload是连续PCM_U8，正常为160字节。`sample_index`是payload首样本的绝对序号。音频帧不要求ACK，也不重传；损坏或过期音频直接丢弃。

ESP32每100 ms发送32字节STATUS，包含：

- `IDLE/PREFILL/PLAYING/DRAINING/MUTED/FAULT`；
- 静音状态；
- 缓冲样本数和容量；
- underrun、overrun、CRC错误和音频序号缺口；
- GPTimer过期样本跳过数；
- 最近音频帧距今毫秒数。
- 偏移 30～31 的小端 `u16` 目标音量（千分比）；仅当能力位 bit 2 存在时解释。

音量达到 0 后，`STATUS.muted` 为真，但实时流可以继续处于 `PLAYING` 并消耗缓冲；调高音量无需重新预缓冲。录音、频谱和系统回环活动门限都基于调节前的 PCM，音量滑块不改变这些读数。

ESP32在PREFILL状态等待至少960样本（120 ms）。该水位用于覆盖普通的 Windows、Python 与 USB 调度长尾，同时仍为2048样本缓冲保留1088样本余量。播放中若缓冲耗尽，立即停止PWM并回到PREFILL；超过500 ms没有收到有效音频时保持流接收能力并回到PREFILL，下一批音频完成预缓冲后可自动恢复。主机同时会对旧固件的超时MUTED状态重新发送STREAM_START。

## 7. 云台复用

`GIMBAL_SETPOINT` payload为两个小端有符号int16：

```text
pan_centidegrees, tilt_centidegrees
```

范围均为 `-9000..9000`。电脑端串口只有一个所有者；音频服务和控制服务都向 `SerialDeviceLink` 发布消息，不能各自打开同一个COM口。

## 8. 源码入口

| 文件 | 职责 |
|---|---|
| `src/vision_gimbal/audio/preprocessor.py` | 电脑端完整DSP流水线 |
| `src/vision_gimbal/audio/recording.py` | 限幅后PCM16 WAV监听录音 |
| `src/vision_gimbal/application/audio_service.py` | 音源切换、采集队列、20 ms聚包和生命周期 |
| `src/vision_gimbal/infrastructure/sounddevice_microphone.py` | 麦克风与立体声混音共用的 PortAudio 采集适配器 |
| `src/vision_gimbal/infrastructure/wasapi_process_loopback.py` | 原生进程回环辅助程序的 Python 生命周期、10 ms分块、停滞检测与自动重启 |
| `native/wasapi_process_loopback/main.cpp` | 事件驱动的 Windows 进程回环捕获、PCM16到float32转换和独立10 ms静音时钟 |
| `src/vision_gimbal/protocol/` | Python帧、消息和CRC |
| `src/vision_gimbal/infrastructure/serial_device_link.py` | 唯一串口所有者、重连、ACK和复用 |
| `src/full_size/src/protocol/` | ESP32 COBS、CRC和协议服务器 |
| `src/full_size/src/audio/flash_audio_source.*` | 内置Flash音频 |
| `src/full_size/src/audio/stream_audio_source.*` | 2048样本实时环形缓冲 |
| `src/full_size/src/modulation/audio_modulator.*` | PCM样本到PWM duty查表 |
| `src/full_size/src/app/ultrasonic_app.*` | 任务、状态机、超时和硬件调度 |

## 9. 验收顺序

1. 不接12 V，仅验证HELLO、ACK、STATUS和云台帧；
2. 电脑发送数字生成的1 kHz、低幅PCM，检查缓冲无欠载；
3. 示波器确认GPIO4载波、占空比变化和停止行为；
4. 单驱动、单换能器逐级验证；
5. 分别启用麦克风、立体声混音和进程回环；
6. 将 Windows 物理扬声器静音，确认进程回环频谱与阵列音频仍正常；
7. 连续运行30分钟，要求CRC、overrun、underrun和timer skip均为0；
8. 最后根据实测声压确认 LOUD + BOOST 是可连续使用的最大允许档。

若出现“内置音频清楚、实时流不清楚”，先按 [13-实时音频传输排查.md](13-实时音频传输排查.md) 使用同字节、同模式文件流对照，并保存完整状态日志。

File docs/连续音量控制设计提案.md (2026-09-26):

# 连续音量控制设计与实现

> 状态：已实现；硬件阵列上的实际声压曲线仍需测量。适用入口：`src/vision_gimbal` 桌面端与 `src/full_size` 正式固件。

## 目标和范围

- 桌面端提供 0～100% 滑块，播放时可连续调节，无须停止、重新预缓冲或重建音源。
- 同一主音量作用于麦克风、立体声混音、WASAPI 进程回环和固件内置 Flash PCM。
- 0% 最终使 GPIO4 超声 PWM 占空比为 0；“关闭音频链路”和现有故障静音仍独立生效，且优先级更高。
- 固定载波和测试纯音是台架诊断路径，暂不受主音量影响。它们仍由原有的显式启动、停止命令控制。
- 100% 等于当前音频输出基线；音量控制只衰减，不提升现有最大调制深度。

这里的百分比是用户控制位置，不是经过校准的声压级。非零音量主要改变可听音频的调制深度；DSB-AM 的载波基线仍存在，不能把滑块当作超声暴露或功率保护装置。

## 放置位置

```text
实时音源 → PC 滤波/重采样/自动电平/压缩/限幅 → PCM_U8 ─┐
                                                        ├→ ESP32 RAW/LOUD
固件 Flash PCM ──────────────────────────────────────────┘         ↓
                                                   主音量与渐变（共同路径）
                                                              ↓
                                               DSB-AM/SRAM → PWM duty → GPIO4
```

主音量放在固件的 `RAW/LOUD` 处理之后、`DSB-AM/SRAM` 查表之前。若放在电脑端慢速电平控制之前，自动电平会抵消音量变化；若放在电脑端量化前，固件的 LOUD 非线性处理会改变滑块响应，而且 Flash PCM 无法共用。不要用调节 12 V 电源、载波频率或 LEDC 整体占空比替代音频音量控制。

固件可将 LOUD 后的 8 位样本转成以 128 为中心的有符号值，乘以当前音量增益，再送入现有调制映射。0% 是特殊状态：不能只发送 PCM 静音值 128，因为现有 DSB-AM/SRAM 映射仍会输出固定超声载波；到达零增益时必须写入 `duty=0`。实时流在 0% 时继续消耗缓冲样本和维护时钟，恢复非零音量时不必重新建立流。

当前控制曲线：非零位置从约 −30 dB 连续映射到 0 dB，0% 为关闭输出。使用单调的分贝映射而非线性幅值映射；实际低端手感应以测量和试听调整。当前传输为 PCM_U8、输出为 10 位 PWM，极低音量的有效分辨率有限，不应承诺每个百分比都有可分辨的声压变化。

## 控制和状态流

```mermaid
flowchart LR
  UI[AudioPanel 音量滑块] --> Intent[SetAudioVolume 意图]
  Intent --> Runtime[ApplicationRuntime 最新值槽]
  Runtime --> Service[AudioService 目标音量]
  Service --> Link[SerialDeviceLink]
  Link -->|SET_VOLUME + ACK| App[UltrasonicApp 播放任务]
  App --> Engine[ModulationEngine 渐变状态]
  Engine --> Mod[AudioModulator]
  App -->|STATUS| Link
  Link --> Service
  Service --> UI
```

1. `AudioPanel` 显示百分比和 0% 的“静音”字样。拖动时最多每 50 ms 发布一次最新值，松手立即发布最终值。滑块的鼠标滚轮事件转交侧栏滚动区域，避免浏览面板时误调音量。
2. 新增独立的 `SetAudioVolume` 意图和 `AudioService.set_volume()`。音量不放进现有 `AudioModeSettings`，因为 `AudioService.configure()` 会重启正在运行的流。应用层和串口层只保留尚未发送的最新音量，防止拖动产生无界控制队列。
3. `SerialDeviceLink` 保存期望音量，串口重连后先重发音量，再发 `STREAM_START`。一个可靠命令仍须等其 ACK 后才发送下一个可靠命令；音频帧可按现有机制继续发送。`SET_MUTE` 和 `STREAM_STOP` 的停止语义优先于音量变化。
4. 固件协议任务验证音量范围并入队；播放任务独占当前增益、目标增益和驱动写入。以约 40 ms（8 kHz 下 320 个样本）渐变，避免每次拖动产生突变。`skipFrames()` 必须按跳过的样本数推进渐变，否则定时积压时音量变化会被拉长。
5. `SET_VOLUME` 在流停止、音源切换和活动门限暂停期间仍更新目标；Flash PCM 使用同一增益。无桌面端时可用台架文本命令 `V0`～`V100` 调节 Flash 播放。

## 协议增量

保留当前帧格式和协议版本 1，增加可协商能力：

| 字段 | 设计 |
|---|---|
| `HELLO_ACK` 能力位 | 新增 bit 2：支持主音量；旧固件的 `0x00000003` 保持可识别 |
| `SET_VOLUME` | 消息类型 `0x08`，PC→ESP，可靠控制命令 |
| payload | 小端 `u16 volume_permille`，允许 `0..1000`；越界或长度错误以错误 ACK 拒绝 |
| `STATUS[30:32]` | 利用当前保留的两个字节回报固件接受的目标音量；仅在能力位存在时解释 |

新桌面端遇到没有音量能力位的旧固件时，禁用滑块和音频启动按钮，并在 `AudioService.start_transmitting()` 处再次拒绝启动；若启动请求发生在握手完成之前，`SerialDeviceLink` 也会在确认能力位之后才允许发送 `STREAM_START`。这样自动启动或其他调用不会使设定的初始音量失效、却以 100% 播放；视觉和云台功能可继续使用。旧桌面端连接新固件时，固件沿用原有 100% 默认音量，维持现有 Flash 和实时播放行为。新桌面端从 `[audio.volume]` 读取初始值（当前 50%），并在首次 `STREAM_START` 之前下发。

## 与现有静音和显示的关系

- `volume=0` 时实时缓冲仍可处于 `PLAYING`；`STATUS.muted=true` 应在增益渐变完成且 PWM 关闭后回报。不要因此把流状态改为 `MUTED`，否则桌面端现有的 `_device_stream_needs_rearm()` 会把它误判为需要重建的流。
- `SET_MUTE(true)`、`STREAM_STOP`、欠载、超时和驱动错误仍立即按现有路径关闭 PWM；音量上升不能取消这些状态。
- 进程回环活动门限继续基于音量控制前的 `post_limiter_samples` 判断真实输入活动，否则 0% 会被误认为音源数字静音。现有录音和频谱抽头也保留在音量控制之前，并在界面注明它们显示的是输入音频，不是阵列声压。
- UI 状态同时保留“期望音量”和固件确认的目标音量；重连期间显示等待同步，不把滑块位置当作已经生效的硬件状态。

## 实现位置

| 层 | 文件 | 主要变化 |
|---|---|---|
| UI / 应用 | `src/vision_gimbal/ui/audio_panel.py`、`src/vision_gimbal/ui/main_window.py`、`src/vision_gimbal/ui/presenter.py`、`src/vision_gimbal/ui/view_models.py`、`src/vision_gimbal/domain/intents.py`、`src/vision_gimbal/application/runtime.py` | 滑块、意图、状态显示和最新值合并 |
| 音频服务 | `src/vision_gimbal/domain/audio.py`、`src/vision_gimbal/application/audio_service.py`、`src/vision_gimbal/config/schema.py`、`configs/vision_gimbal.toml` | 音量合同、初始值、状态和独立控制方法 |
| 传输 | `src/vision_gimbal/ports/device_link.py`、`src/vision_gimbal/infrastructure/serial_device_link.py`、`src/vision_gimbal/protocol/messages.py`、`src/vision_gimbal/infrastructure/null_device_link.py` | 新命令、能力位、ACK、重连恢复和队列合并 |
| 固件 | `src/full_size/src/protocol/*`、`src/full_size/src/app/ultrasonic_app.*`、`src/full_size/src/modulation/modulation_engine.*`、`src/full_size/src/modulation/audio_modulator.*` | 验证、状态、渐变、两类音源共用处理和零音量 PWM 关闭 |

## 验收重点

1. 单元测试覆盖 `0/1/50/100%`、音量曲线单调、越界拒绝、RAW/LOUD 与 DSB-AM/SRAM、音源切换与串口重连、控制队列合并；拖动音量不产生新的 `STREAM_START`。
2. 固件验证 Flash 与实时 PCM 对同一音量命令都有响应；0% 的 GPIO4 无 40 kHz 切换，而缓冲仍持续前进；从 0% 恢复时无需重新预缓冲。
3. 不接 12 V 时先检查协议 ACK、STATUS、GPIO4 duty 和渐变时长；随后按现有单驱动到整阵列步骤验证，并观察快速拖动和 0% 往返是否出现明显瞬态。
4. 验证调低音量不会被电脑端自动电平或固件 LOUD 模式补偿，也不会改变进程回环的静音活动门限。实际百分比与可听声压关系需用合适仪器实测校准。

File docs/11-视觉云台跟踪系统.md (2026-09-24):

# 视觉云台跟踪系统

> 版本：v1.4
> 日期：2026-09-24
> 正式入口：`python -m vision_gimbal`

当前桌面程序已经拆分为 PySide6 UI、视觉流水线、控制状态机和硬件传输层。闭环为：

```text
摄像头 → YOLO人体检测 → ByteTrack轨迹ID → 逐轨迹Kalman
→ CPU服饰特征抽样与会话人物ID → 用户在UI中选择目标
→ 近距离瞄准策略 → 像素偏差转角度
→ 双轴PI速度请求 ─┐
                  ├→ 控制仲裁 → 统一限速/限加速度/软限位
停止状态下WASD ────┘→ 共享二进制串口 ─→ ESP32 `(pan,tilt)` → 云台
                                       └→ ESP32 8 kHz 调制 → 超声阵列
麦克风 → DSP → 8 kHz PCM_U8 → 音频分包 ─┘
             └→ 后台增量 STFT → UI 实时发送频谱（dBFS）
```

视觉层只报告人物轨迹及会话内人物 ID；自动追踪和 WASD 都不能直接访问串口。`ControlService` 是唯一云台命令出口，因此两种控制模式不会同时生效。

## 运行

桌面 UI 需要 Python 3.10～3.12；当前开发机建议直接使用 Python 3.11。先同步依赖：

```powershell
uv sync --locked --python 3.11
```

只观察算法、不连接云台：

```powershell
$env:PYTHONPATH = ".\src"
uv run python -m vision_gimbal
```

连接ESP32，例如串口为`COM5`：

```powershell
$env:PYTHONPATH = ".\src"
uv run python -m vision_gimbal --serial-port COM5
```

波特率默认 460800，与 `src/full_size/full_size.ino` 一致。云台和实时音频由同一个 `SerialDeviceLink` 通过二进制协议复用；程序按 10 Hz 控制节拍发布目标角度，串口断开时后台自动重连，不阻塞 YOLO。主要运行参数位于 `configs/vision_gimbal.toml`，命令行的串口、波特率、摄像头索引和推理设备参数可以覆盖配置文件。

当前配置默认启用音频控制面板，但不会自动打开麦克风。仍可在不配置串口时运行视觉仿真；此时麦克风链路的开始按钮保持禁用。

## UI 操作

- 程序启动后默认处于“停止追踪 / 手动控制”状态，但摄像头和人物识别继续运行。
- 单击画面中的人物框将其选中；蓝框表示已选中但尚未生效的目标。
- 单击“开始追踪”后才进入自动闭环；黄色框表示当前实际追踪目标。
- 自动追踪中点击另一个人只会形成待切换目标，再单击“切换目标”才会生效，避免误点导致云台突然转向。
- 单击“停止追踪”会退出视觉闭环并保持最后指令角度，不会关闭摄像头或切断舵机电源。
- 停止状态下可按住 `W/A/S/D` 控制上、左、下、右；自动追踪中这些按键会被忽略。
- 窗口失去焦点时会自动释放全部方向键，避免按键卡住后持续转动。
- 黄色框表示当前活动目标，红色十字表示阵列瞄准中心。
- 紫色斜十字表示实际送入PI的瞄准点；近距离模式触发后它会移至人体框约30%高度。
- 虚线人物框表示 Kalman 短期预测，目标丢失超时后系统停止追踪，不会自动换到其他人物。
- 同一人离开后再出现，新轨迹经连续两次外观匹配可复用原人物 ID；目标丢失超时后仍需重新点击“开始追踪”。`ID ?` 表示尚未取得可用特征，暂不能选中。

### 会话内人物重认

`[vision.appearance]` 默认开启。新轨迹最多取四次合格特征确定人物 ID；旧人物需要连续两次匹配才可复用编号。已有轨迹每隔 `sample_interval_s` 抽样一次，预测框不抽样。外观特征由 OpenCV 在 CPU 上计算，取人体框中央区域的上下服饰颜色与亮度直方图。身份库在程序关闭时清空，离场人物默认保留 `gallery_ttl_s = 120` 秒。相似衣着、换装、背光和大面积遮挡会降低可靠性；匹配阈值应使用实际摄像头录像校准。

### 实时音源与超声阵列

- 串口连接后，可选择“麦克风”、“电脑声音（立体声混音）”或“电脑声音（静音无关回环）”，再单击“开始音频链路”。
- 默认使用进程回环：它捕获本程序之外的 Windows 渲染音频，即使物理扬声器静音，数字音频仍可送往阵列。
- 进程回环 helper 异常退出或连续 1 s 没有输出 PCM 块时会自动重建；短暂中断导致设备超时后，主机也会重新建立音频流。
- 单击“关闭音频链路”会先停止采集，再请求 ESP32 静音并停止流，最后释放当前音源；视觉识别和云台控制继续运行。
- 传输中切换音源会丢弃旧音源的排队数据，重置 DSP 和样本序号，再建立新流；迟到的旧采集回调不会进入新流。
- 进程回环数字静音 1 s 后会停止 ESP32 流与 PWM，有新内容时自动重新预缓冲，避免无可听内容时长期发射载波。
- `RAW / LOUD`、`STANDARD / BOOST`、`DSB-AM / SRAM` 均可在右侧面板即时切换。若音频正在传输，程序会自动停止并用新参数重新建立音频流，不会重启摄像头、YOLO 或舵机控制。
- 面板显示 ESP32 播放状态、缓冲样本数、欠载和主机丢包。连续出现欠载或丢包时，先处理串口吞吐和系统调度问题，不要继续增加增益。
- 画面下方的实时频谱取自电脑端限幅后、PCM_U8 量化前的 8 kHz 发送音频，以固定 dBFS 色标显示最近数秒的时频变化。它不是 40 kHz 超声载波测量，也不是经过声压标定的 dB SPL。
- 频谱 FFT 在独立有界线程中运行；分析来不及时只丢弃旧的可视化音频块，不阻塞串口音频、视觉识别或云台控制。关闭音频链路后频谱会清空并回到等待状态。
- `LOUD` 是 ESP32 端响度映射，`BOOST` 会提高包络峰值。当前电脑声音默认为 `LOUD + BOOST + DSB-AM` 最大允许档；首次接入功放和阵列时仍应从 `RAW + STANDARD + DSB-AM` 完成低能量验证。

默认模式也可在 `configs/vision_gimbal.toml` 的 `[audio.stream]` 中设置：

```toml
processing = "loud"      # raw 或 loud
boost = true              # false=STANDARD，true=BOOST
modulation = "dsb_am"    # dsb_am 或 sram
```

实时频谱参数位于 `[audio.spectrum]`：

```toml
enabled = true
window_ms = 40.0
hop_ms = 20.0
history_s = 6.0
refresh_hz = 10.0
min_dbfs = -80.0
max_dbfs = 0.0
queue_blocks = 4
```

当前发送采样率为 8 kHz，因此频谱纵轴固定为 0～4 kHz；默认语音低通为 3 kHz。`queue_blocks` 只限制频谱分析队列，不改变麦克风采集队列或串口发送队列。

## 标定

- 当前装机配置已将视觉水平轴反向；垂直轴方向保持不变。
- 首次装机必须校准水平/垂直视场角、瞄准点偏移、两轴方向和机械限位。
- PI默认参数偏保守；先只调`Kp`，稳定后再小幅增加`Ki`。舵机堵转或供电不足不能通过PID解决。
- 不配置`--serial-port`时仍会完整运行控制计算，但不会驱动硬件。

配置中的 `last_commanded_pose` 和 UI 中的“指令角度”不是舵机编码器反馈。当前硬件没有角度回读，程序只能显示最后下发的目标角度。

正式实现位于 `src/vision_gimbal`：

- `domain`：不可变数据合同与状态枚举；
- `vision`：YOLO、ByteTrack、重复框过滤和逐 ID Kalman；
- `control`：显式目标锁定、近距离策略、PI、WASD、仲裁和运动限制；
- `application`：视觉服务、会话状态机和唯一命令出口；
- `infrastructure`：OpenCV 摄像头、串口和空云台适配器；
- `ui`：PySide6 窗口、坐标映射、绘制和线程适配。

旧 `src/cv_test_deprecated` 算法文件暂时保留用于回归参考。实时麦克风可从同一桌面 UI 手动启停，也可使用 `utils/mic_stream_cli.py` 独立测试。

## 近距离上半身瞄准

当锁定人体的框高达到画面高度90%、且接触画面上/下边缘并持续5个真实检测帧时，系统切换到近距离模式。它保留水平瞄准点，仅将垂直瞄准点从框中心改到框高约30%处，使现有垂直PI向上重构图。框高低于70%、上下边缘都完整可见并持续10帧后才退出，避免在阈值附近反复切换。

这些参数位于 `configs/vision_gimbal.toml` 的 `[close_range]`。Kalman 预测帧不会触发近距离状态切换；停止、切换目标或目标丢失超时都会清空近距离状态。

## 安全边界

“停止追踪”表示停止视觉自动控制并让云台保持最后角度，不是硬件急停，也不会释放舵机扭矩。需要物理急停或断电保护时，必须扩展 ESP32 协议和硬件电源控制。

## 低频深度与相对声场分析

`[spatial_field]` 是默认关闭的附加显示功能。它每隔一段时间只提交一张最新相机帧给后台线程，队列容量固定为一；分析来不及完成时会丢弃旧帧，绝不积压或阻塞 YOLO、10 Hz 云台控制、串口和实时音频。

该功能不会产生任何云台、音频或 ESP32 指令。深度图只在后台用于计算，UI 不单独展示它；主视频保持原有跟踪与交互，独立的“声场模拟”页显示同一摄像头画面及其半透明相对声场热图。声场图中不显示来源帧、推理耗时或其他角标。它是可见表面的**直达、相对自由场**估计，不是 dB SPL 测量，未包含房间反射、遮挡后的场、空气非线性或阵面实测修正。

相机内参由 `[camera.calibration]` 给出，配置中的 `fx=fy=1450`、`cx=960`、`cy=540` 对应 1920×1080。程序会按当前相机分辨率缩放这些值；在当前 1280×720 配置下等效为 `fx=fy=966.67`、`cx=640`、`cy=360`。畸变系数顺序与 OpenCV 一致：`k1, k2, p1, p2, k3`。

首次启用前，需要准备 320×192 的 OpenVINO 深度模型。安装可选运行时并从模型目录导出：

```powershell
uv sync --locked --extra spatial
New-Item -ItemType Directory -Force models
Push-Location models
uv run python -c "from ultralytics import YOLO; YOLO('yolo26n-depth.pt').export(format='openvino', imgsz=(192, 320))"
Pop-Location
```

### 深度时序稳定

声场面板只显示深度推理所用的来源帧及其热图，不再把旧热图叠加到最新视频帧，因此云台或相机运动不会造成错帧跳变。后台会在低分辨率深度图上执行保守的对数域时序稳定：仅当两帧大面积重叠且残差一致时，才做受限的全局尺度校正；校正后仍相近的像素才指数平滑，局部大变化、无效值、分辨率变化和超过 `max_gap_s` 的断帧直接采用新值或重置状态。

参数位于 `[spatial_field.depth.temporal]`。`interval_s` 默认设为 0.5 s；应根据实际 P95 推理耗时调大，避免后台长期满载。该稳定器不估计相机运动，因此它改善的是静态或缓慢变化视角下的单目尺度闪烁；若需要在快速云台运动中保持地图连续，应在后续版本接入云台姿态重投影或光流对齐。

导出目录应为 `models/yolo26n-depth_openvino_model`，与默认配置一致。确认 Intel Arc 图形驱动可被 OpenVINO 检出后，将 `spatial_field.enabled` 改为 `true`。若 320×192 仍超出性能预算，使用 256×160 重新导出模型并同步修改 `input_width`、`input_height`；静态 OpenVINO 模型不能安全地在运行中变更输入大小。

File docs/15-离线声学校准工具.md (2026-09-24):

# 离线声学校准工具

日期：2026-09-21。工具入口是 `utils/audio_calibration/calibrate.py`。它只处理文件，不接入 `src/vision_gimbal` 的 Qt、视觉或实时音频流程。

## 1. 环境与入口

在仓库根目录同步现有锁定环境：

```powershell
uv sync --locked --python 3.11
```

所有命令使用同一入口：

```powershell
uv run python .\utils\audio_calibration\calibrate.py --help
```

工具仅依赖已在 `pyproject.toml` 锁定的 NumPy 和 Python 标准库；不需要新的包。测试代码在 `tests/test_audio_calibration.py`，可运行：

```powershell
uv run python -m pytest -q tests/test_audio_calibration.py
```

## 2. 生成训练和测试激励

以下命令生成多音、带限噪声、不同输入峰值和不同随机种子的 8 kHz PCM_U8 激励。每个 take 都含：

```text
input.wav       实际 PCM_U8 WAV
input_u8.bin    将要发送的原始字节
input.h         可交给 audio_stream_probe.py 的 C++ 头文件
metadata.json   峰值、RMS、种子、SHA256 和固定播放设置
```

```powershell
uv run python .\utils\audio_calibration\calibrate.py prepare `
  --output .\output\audio_calibration\session_001 `
  --kinds multitone noise `
  --peaks 0.10 0.20 0.40 0.60 `
  --seeds 12 `
  --duration-s 8 `
  --processing raw --drive standard --modulation dsb
```

`prepare` 选项：

| 选项 | 默认值 | 作用 |
|---|---:|---|
| `--output` | 必填 | 新实验目录 |
| `--kinds` | `multitone noise` | 可选 `multitone`、`noise`、`chirp` |
| `--peaks` | `0.10 0.20 0.40 0.60` | 量化前请求的输入峰值，必须不超过 0.98 |
| `--seeds` | 6 | 每种信号和峰值的独立随机种子数量 |
| `--duration-s` | 8 | 每个信号的秒数 |
| `--low-hz` / `--high-hz` | 250 / 3000 | 激励频带 |
| `--processing` | `raw` | 记录 RAW 或 LOUD；辨识建议 RAW |
| `--drive` | `standard` | `standard` 或 `boost`；两档必须分别建模 |
| `--modulation` | `dsb` | `dsb` 或 `sram`；两种模式必须分别建模 |

命令会创建 `manifest.json`，按完整信号种子分入 train、validation、test。它不会使用或覆盖根目录 `data/` 的 WAV。

## 3. 播放、录音和配对

固定阵列位置、麦克风位置、录音增益、载波、RAW/LOUD、STANDARD/BOOST 和 DSB/SRAM。关闭录音端 AGC、降噪和回声消除。每一个 take 将独立麦克风原始录音保存为对应目录的 `recorded.wav`，例如：

```text
output/audio_calibration/session_001/multitone_a0.20_s03/recorded.wav
```

录音可为 8/16/24/32 bit PCM WAV。推荐 48 kHz；程序会做带限 48 kHz→8 kHz 降采样。它不录制麦克风，也不声明手机麦克风或普通声卡对 40 kHz 场一定线性。

发送时复用现有诊断工具，每次只播放一个 take，并将其串口日志保存到 take 目录：

```powershell
uv run python .\utils\audio_stream_probe.py `
  --serial-port COM5 `
  --audio-header .\output\audio_calibration\session_001\multitone_a0.20_s03\input.h `
  --processing raw --drive standard --modulation dsb `
  --repeats 1 `
  --log-jsonl .\output\audio_calibration\session_001\multitone_a0.20_s03\stream.jsonl
```

替换 `COM5` 为实际端口。此工具必须没有发生 underrun、overrun、CRC、sequence gap、timer skip 或 host drop 才能接纳该 take；发生任一异常则重录。`calibrate.py` 当前从声学波形估计固定延迟，不能替代前后同步标记对长录音的时钟漂移校正。因此，首轮请保持每条录音约 8 秒，并在录音软件里裁掉播放前后的长静音；有同步标记或已测时钟比例时，应先在外部处理后再将配对段交给本工具。

## 4. 拟合

所有 `recorded.wav` 就位后执行：

```powershell
uv run python .\utils\audio_calibration\calibrate.py fit `
  --manifest .\output\audio_calibration\session_001\manifest.json `
  --model .\output\audio_calibration\session_001\model_p123.npz `
  --orders 1 2 3 --taps 128 --ridge 0.001 --oversample 6
```

模型为固定参数并联 Hammerstein：

\[
\hat y[n]=c+\sum_{p\in P}h_p*\phi_p(x)[n].
\]

`phi_p` 先把 8 kHz 输入固定重建到较高采样率，计算 p 次幂后低通并回到 8 kHz。这避免直接在 8 kHz 平方造成的二次谐波混叠。`--oversample 6` 对应 48 kHz 特征处理；设为 1 可用于很快的低保真调试。

| 选项 | 默认值 | 作用 |
|---|---:|---|
| `--manifest` | 必填 | `prepare` 输出且已配对录音的清单 |
| `--model` | 必填 | 输出 `.npz` 模型；同名 `.report.json` 保存报告 |
| `--orders` | `1 2 3` | 保留的一、二、三阶分支；先比较 `1`、`1 2`、`1 2 3` |
| `--taps` | 128 | 每分支固定 FIR 长度，8 kHz 下约 16 ms |
| `--ridge` | 0.001 | L2 正则化；仅用验证集选取 |
| `--oversample` | 6 | 特征重建倍数；训练与预失真必须一致 |
| `--batch-size` | 4096 | 正规方程的分块样本数，内存紧张时减小 |
| `--low-hz` / `--high-hz` | 250 / 3000 | 报告 NMSE 的评估带宽 |

运行后先看 `validation` 的平均 NMSE，以及 `.report.json` 中按 take 列出的 NMSE、对齐延迟和 RMS。不要按训练集最低误差选模型，也不要因模型复杂就默认更好。

## 5. 冻结模型后的评估

只有在验证集选定模型和参数后，才检查 test 内容：

```powershell
uv run python .\utils\audio_calibration\calibrate.py evaluate `
  --manifest .\output\audio_calibration\session_001\manifest.json `
  --model .\output\audio_calibration\session_001\model_p123.npz `
  --split test `
  --output .\output\audio_calibration\session_001\test_report.json
```

`evaluate` 的 `--split` 可关闭，从而输出全部集合；`--low-hz` 和 `--high-hz` 与拟合报告相同。报告的 NMSE 是固定对齐、固定频带内实测输出相对模型预测的误差；它不是 THD 或绝对声压指标。

## 6. 离线预失真

线性基线保留一阶支路，并使用其完整固定特征链的解析梯度做投影迭代。这样 `--oversample 6` 的特征重建也被包含在补偿中：

```powershell
uv run python .\utils\audio_calibration\calibrate.py predistort `
  --model .\output\audio_calibration\session_001\model_p123.npz `
  --target .\data\human_test\test1.wav `
  --output .\output\audio_calibration\predistorted_test1 `
  --method linear --regularization 0.001 --peak-limit 0.60
```

`--target` 可为任意 PCM WAV；它只作为目标，绝不自动加入训练集。输出目录包含可播放的 `input.wav`、`input_u8.bin`、`input.h` 和量化后模型预测的 `predistort_report.json`。

`--method nonlinear` 使用完整模型的解析梯度进行投影迭代，选项为 `--iterations`（默认 40）、`--step-size`（默认 0.5）、`--energy-weight`（默认 0.0001）和 `--peak-limit`（默认 0.60）。在线性模式下，`--regularization`（默认 0.001）是对应的一阶模型输入能量正则化。它是离线实验功能：真实重放后仍需录音，并以与原始输入、线性均衡相同的目标声级比较。模型预测改善不构成真实失真改善的证据。

`--peak-limit` 必须保持在训练数据覆盖的输入范围内。目标不可达时降低目标声级或补采数据，不通过增大峰值或开启 LOUD 来规避限制。

## 7. 根目录 data 的冒烟测试

`data/` 中的 WAV 没有配对输入、录音条件和音量配比，禁止作为训练清单。它们可以只用于读入、降采样和特征计算的冒烟测试：

```powershell
uv run python .\utils\audio_calibration\calibrate.py smoke `
  --wav .\data\human_test\test1.wav `
  --wav .\data\linear\linear_chirp_250Hz_to_3000Hz_10s.wav
```

`smoke` 不读取 manifest、不写模型、不拟合，也不把这些文件复制到输出目录。

## 8. 不变性边界

一个模型只对应一组固定条件。以下任一变化都需要新 session 和新模型：RAW/LOUD、STANDARD/BOOST、DSB/SRAM、载波频率、阵列或麦克风的位置/角度、录音增益、明显不同供电或温度状态。该工具不把这些状态混合到同一个模型中。

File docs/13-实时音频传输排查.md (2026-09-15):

# 实时音频传输排查

> 版本：v1.2
> 日期：2026-09-14

适用现象：普通音箱播放量化后的 WAV 清楚，转换为内置 `audio_data.h` 后阵列也能清楚播放，但实时麦克风流不清楚。

## 已定位的实现差异与问题

1. 内置播放在固件复位后的默认值是 `DSB + LOUD + BOOST`，旧版实时麦克风流曾固定请求 `DSB + RAW + STANDARD`；当前实时链路由配置/UI选择模式，项目配置已改为 `DSB + LOUD + BOOST`。转换工具还会去直流、归一化和淡入淡出。因而必须用同样的 PCM 字节和同样的模式比较，才能隔离传输因素。启动过实时流后，固件的模式可能已经改变，内置对照应明确指定模式。
2. 固件只缓存最近一条可靠命令的 ACK。旧电脑端连续发送 `STREAM_START` 和 `SET_MUTE` 时，如果启动 ACK 丢失，后一个 ACK 会覆盖缓存；随后重试启动命令会清空音频缓冲。这已在模拟串口测试中复现，修复后同一启动命令只执行一次。电脑端现按顺序等待可靠命令 ACK，普通音频帧不要求 ACK。
3. 本机 Arduino-ESP32 3.3.10 的 HardwareSerial 默认接收环形缓冲只有 256 字节，常规音频帧约 185 字节，主机积压时可能连续发送多个包。固件现将 UART RX 缓冲增至 4096 字节；这是缓解突发/调度阻塞的措施，不代表已证明现场发生 UART 溢出。该缓冲与 2048 样本的解码后音频缓冲不同，USB CDC 不应用此 UART 设置。
4. 旧命令行未显示 CRC、音频序号缺口和 GPTimer 跳样；现已补齐，视觉界面的串口详情也会显示 under/over/crc/gap/skip/host_drop。
5. 当其他错误计数稳定而只有 under 增长时，60 ms工作水位不足以覆盖偶发的 Windows、Python 或 USB调度长尾。当前默认预缓冲已提高到120 ms；完整UI中的可选声场推理也恢复为默认关闭，减少与实时音频线程的资源竞争。

## 用内置 PCM 做串口对照

在仓库根目录运行，以下 `COM5` 替换为实际 ESP32 串口。先退出其他占用串口的程序，包括视觉界面和 Arduino 串口监视器。

不接触设备，仅检查文件格式和样本哈希：

```powershell
uv run python .\utils\audio_stream_probe.py --inspect-only
```

默认读取 `src/full_size/src/data/audio_data.h`，可用 `--audio-header` 覆盖。工具读取十进制 `kAudioSamples` 数组，**不重新归一化、不经过麦克风 DSP**；每包最多 160 样本，以 8 kHz 速率发送，默认重复 3 次。末尾追加超过一整个设备音频缓冲的静音，避免停止命令截断原音频；这个静音尾段不是音频源的一部分。

先明确内置对照：在固件未建立二进制会话时，用串口字母命令选择 `D R N P`（DSB、RAW、STANDARD、播放一次）。已经建立二进制会话时，需要退出电脑串口程序并复位固件才能再使用字母命令。随后关闭串口监视器，运行匹配的串口播放：

```powershell
uv run python .\utils\audio_stream_probe.py --serial-port COM5 --processing raw --drive standard --log-jsonl .\output\probe_raw_standard.jsonl
```

再比较内置 `D E B P` 与下列同模式串口播放：

```powershell
uv run python .\utils\audio_stream_probe.py --serial-port COM5 --processing loud --drive boost --log-jsonl .\output\probe_loud_boost.jsonl
```

LOUD/BOOST 是与内置默认值对齐的对照条件；对照命令不会改写实时链路配置。没有特别改过的内置播放通常是 DSB；只有对照明确使用 SRAM 时，才加 `--modulation sram`。

当前工具默认使用120 ms预缓冲。如需确认更长的调度停顿，可在同一模式下再比较180 ms预缓冲：

```powershell
uv run python .\utils\audio_stream_probe.py --serial-port COM5 --processing loud --drive boost --prebuffer-ms 180 --log-jsonl .\output\probe_prebuffer180.jsonl
```

较大的预缓冲只能缓解有限抖动，不能修复持续丢包、CRC 错误和 GPTimer 跳样。工具遇到断连、状态过期、设备异常静音或从未报告 PLAYING 时会报告失败并停止；不会把“电脑发完字节”当成设备正常播放的证明。

## 麦克风实时流日志

```powershell
uv run python .\utils\mic_stream_cli.py --serial-port COM5 --log-jsonl .\output\mic_stream_diagnostic.jsonl
```

这条命令只启动麦克风，不启动视觉和云台跟踪。日志每秒保存一次完整状态，文件含相对时间，可比较计数增量。处理与驱动模式读取 `configs/vision_gimbal.toml`；当前整机配置为 `LOUD + BOOST`，应使用相同模式的文件流比较。

立体声混音使用相同诊断入口：

```powershell
uv run python .\utils\mic_stream_cli.py --serial-port COM5 --source stereo_mix --log-jsonl .\output\stereo_mix_diagnostic.jsonl
```

物理扬声器静音后仍应采到电脑声音的诊断入口：

```powershell
uv run python .\utils\mic_stream_cli.py --serial-port COM5 --source system_loopback --log-jsonl .\output\system_loopback_diagnostic.jsonl
```

进程回环在真实数字静音持续1秒后会主动停止ESP32流，此时 `IDLE/MUTED` 或界面的“等待电脑声音”是正常结果；开始播放内容后应重新进入 `PREFILL`，随后变为 `PLAYING/False`。Windows主音量静音不应触发这个门控。

## 日志判读

| 终端字段 | 含义与判断 |
|---|---|
| `state / muted` | 正常持续播放应为 `PLAYING / False`。只看 connected 不够；短暂超时会回到 PREFILL，旧固件的 MUTED 状态由主机自动重建流。 |
| `buffer` | 解码后的 PCM 缓冲，容量 2048 样本。持续贴近 0 易欠载，持续贴近满值易溢出。 |
| `under` | 设备没样本可播；现有固件会关闭 PWM、重新预缓冲，因此会产生断续。 |
| `over` | 设备 PCM 环形缓冲满，拒收新包。不是 UART RX 缓冲溢出的直接计数。 |
| `crc` | 固件解码错误总数，包括 COBS、长度、标识和 CRC 错误，不能全部解释成电气位错误。 |
| `gap` | 有效音频包的样本序号不连续，可能来自主机丢包或途中坏帧。当前固件没有补齐缺失样本。 |
| `skip` | GPTimer 积压而跳过的样本数。若它增长而 crc/gap 为 0，优先检查播放调度和任务阻塞。 |
| `host_drop` | 电脑发送队列满后丢弃旧包。建连等待期间可以增加，重点看稳定播放时是否继续增长。 |
| `capture_drop` | 当前实时音源的采集队列满后丢块；文件诊断工具不使用实时采集。 |
| `capture_restart / capture_age_ms` | WASAPI helper 自动重启次数，以及距最近完整 PCM 块的时间；播放时 age 超过配置门限会触发重建。 |
| `rx_error` | 电脑接收固件状态/ACK 时的帧解码错误。建连的未分帧启动日志也可能增加该数，需看稳定期增量。 |
| `tx_samples / tx_queue` | 主机已交给串口驱动的样本累计数及本地待发送包数，不等于设备实际播放数。 |
| `audio_age_ms` | 固件距最近一次有效 AUDIO_DATA 的时间；默认超过 500 ms 会关闭输出并等待重新预缓冲。 |
| `status_age_ms` | 电脑距最近有效 STATUS 的时间；None 表示从未收到，持续增大说明正在看旧状态。 |
| `late_max_ms` | 仅文件诊断工具显示，电脑发送循环最大调度迟到时间；不是物理 UART 延迟的测量。 |
| `clip` | PCM_U8 量化输入越界计数，不能代替前级压缩器/限幅器触顶比例。 |

应比较稳定播放 10 秒内的计数增量，保留文件头记录的 PCM 哈希、模式与预缓冲参数。

| 对照结果 | 下一步 |
|---|---|
| 同模式内置清楚、文件串口流差，crc/gap 增长 | 查 UART 接收、主机丢包、线缆/连接与固件串口任务是否及时读取。比较原固件与扩大 RX 缓冲后的固件。 |
| 同模式文件流差，只有 skip 增长 | 查 GPTimer 到播放任务的调度和实时流特有负载，增加音频预缓冲不能解决这类跳样。 |
| 文件流 under 增长，180 ms 预缓冲后减少 | 有超过默认120 ms预算的调度/传输抖动；进一步结合 host_drop、late_max_ms 和 gap 定位来源。 |
| 文件流清楚、同模式麦克风流差 | 查实时采集、电脑处理开销、时钟控制、实际信号电平；比较只开麦克风与同时开视觉。 |
| RAW 两种路径都弱或含混，LOUD/BOOST 两种都清楚，错误不增长 | 首要差异是电平/处理模式，不能认定传输损坏。 |
| 同字节、同模式仍不同且全部计数稳定 | 零计数仍不能排除亚样本 PWM 抖动或固件版本差异，下一步测 GPIO 更新间隔并核对板上程序。 |

## 验证范围

仓库中的自动测试覆盖：

- COBS、CRC、帧分片和噪声恢复；
- STREAM_START、ACK 重试和过期 ACK 隔离；
- 状态帧更新时间；
- 云台有符号百分之一度编码；
- 诊断工具发送 PCM 字节和处理模式的一致性；
- 音频预处理、重采样、队列、活动门、录音和频谱；
- 当前视觉、控制、UI 和可选声场服务。

从仓库根目录运行：

```powershell
uv sync --locked --python 3.11
uv run python -m pytest -q
uv run python -m compileall -q src utils
```

测试数量会随实现变化，不在文档中固定写死。pytest 只收集 `tests/`，不依赖 `src/cv_test_deprecated` 的导入副作用。

自动测试仍不能覆盖真实 UART 中断、USB 转串口调度、双核竞争、GPTimer/LEDC 实际更新时间、12 路传播延时、功率温升或声学效果。Arduino 固件必须在锁定的板包版本下另行编译；涉及 UART RX 缓冲或固件状态机的修改必须重新烧录 `src/full_size/full_size.ino`。

历史一次性验证若只存在于被忽略的 `work/` 目录，不应作为其他克隆可复现的仓库证据。需要长期保留的协议桩、脚本和结果应迁入 `tests/` 或受版本控制的证据目录。

最终诊断必须保留实际硬件日志，并记录 Git 提交、固件版本、COM 口、音源、处理模式、运行时长和测量接线。

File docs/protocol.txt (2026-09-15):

我们希望在开始音频时，流式地将预处理好的量化的电脑声音传输到ESP32侧，应当如何做？
流传输协议！
每次我们点击“开始音频流”，会发生什么？
图片：./assets/protocol-sequence.png

重点：
1. 一个命令可能被分在多个帧中，所以要有接收缓冲区
2. 我们的每一帧分为2部分：(1)0x00表示帧开始 (2)COBS编码的不含0x00的帧体
3. 每一帧中，我们的帧体采用二进制，包含如下内容：./assets/frame-structure.png
4. PC端要等windows api返回音效，所以要有音频缓冲

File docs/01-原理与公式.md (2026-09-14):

# 01 · 当前系统的原理、公式与能力边界

> 版本：v2.0
> 日期：2026-09-13
> 适用基线：120 阵元、GPIO4 单相位输出、机械云台转向

本章只解释当前已实现系统。电子相位转向、逐阵元控制和定点聚焦属于未来研究，不是当前功能。

## 1. 从音频到定向可听声

当前数据链为：

```text
可听基带音频
→ 幅度包络
→ 40 kHz PWM 载波
→ 120 个换能器同相辐射
→ 空气非线性产生可听差频
```

可听声不是 ESP32 直接输出的普通扬声器波形。ESP32 只生成超声载波及其包络，可听成分主要由空气传播中的非线性产生。

常用的 Berktay 远场近似可写为：

```text
p_audio(t) ∝ d²(E²(t)) / dt²
```

`E(t)` 是超声包络。这个近似用来理解预处理和失真趋势，不能单独预测实际响度、安全声压或房间中的完整声场。

## 2. 40 kHz 和阵面尺寸

声速取 `c ≈ 343 m/s`、载波 `f_c = 40 kHz`时：

```text
λ = c / f_c ≈ 343 / 40000 ≈ 8.6 mm
```

当前阵面口径约 23 cm，明显大于超声波长，因而同相阵列能在正前方形成比同尺寸普通可听声扬声器更窄的主瓣。

若把阵面粗略视为均匀圆形口径，第一零点半角可用下式作数量级估算：

```text
θ_null ≈ 1.22 · λ / D
```

该结果是理想口径估算。实际结果还受换能器间距、单元方向性、幅相误差、阵面孔洞、安装结构和反射影响。文档和答辩不得把该估算写成已测方向角。

## 3. 当前调制公式

8-bit 无符号 PCM 样本先归一化：

```text
s = (sample - 128) / 128
```

固件提供两种包络：

```text
DSB-AM: E = b + d·s
SRAM:   E = sqrt((b+d)·(b+d·s))
```

这里的 SRAM 是 Square-Root Amplitude Modulation，不是 ESP32 存储器。

| 驱动档位 | `b` | `d` | DSB 包络范围 |
|---|---:|---:|---:|
| STANDARD | 0.45 | 0.40 | 0.05～0.85 |
| BOOST | 0.50 | 0.48 | 0.02～0.98 |

`BOOST` 会增大平均超声输出和器件压力，不能因为它没有提高 12 V 电源电压就将其视为无风险。首次硬件试验使用 `RAW + STANDARD + DSB-AM`。

## 4. 包络到 PWM

对单极性方波，基波幅值与 `sin(πD)` 近似成正比。固件用反正弦查表把包络换成占空比：

```text
D = asin(E) / π
duty = round(1024 · D)
```

10-bit LEDC 周期为 1024 counts，当前最大 duty 限制为 512。驱动层同时设置：

```text
hpoint = (1024 - duty) / 2
```

这使脉冲尽量围绕周期中心对称，减少只移动一条边沿造成的附加相位调制。它不等于已经消除 AM–PM 耦合，最终仍需示波器验证。

## 5. 时间基准和带宽

- 超声载波默认 40 kHz，可在 38～42 kHz 之间以 100 Hz 步进调整；
- 音频更新率固定为 8 kHz，样本周期 125 µs；
- 40 kHz 载波周期约 25 µs，一个音频样本约覆盖 5 个载波周期；
- 8 kHz 采样率的 Nyquist 上限是 4 kHz，当前电脑端低通约为 3 kHz。

固件使用 40 MHz GPTimer 产生 8 kHz 节拍，但 LEDC 更新没有与 40 kHz 载波边界做硬件锁存。因此仍需检查更新抖动、过期样本跳过和可听杂音。

## 6. 方向控制的真实边界

当前 120 个阵元全部接收同一个 GPIO4 波形：

- 没有逐组相位表；
- 没有电子波束转向；
- 没有距离维度的定点聚焦；
- 没有逐组增益或相位校准。

波束在阵面坐标中始终指向法向，系统通过水平/俯仰舵机旋转整个阵面。摄像头、YOLO 和 PI 控制的任务是将这个阵面法向指向选定人体，而不是计算电子相位。

## 7. 声压、响度和测量

声压级定义为：

```text
L_p = 20 log10(p_rms / 20 µPa)
```

注意以下区分：

- `dBFS` 是数字音频相对满量程，不是 dB SPL；
- 电脑端频谱显示的是 8 kHz 基带音频，不是 40 kHz 超声频谱；
- 手机麦克风、自动增益和分贝 App 不能用来校准 40 kHz 声压；
- 定向性必须在固定距离下测方向扫描，不能只比较两个随意点。

## 8. 理论、仿真和实测的标记

| 标记 | 含义 | 可否当作项目成绩 |
|---|---|---|
| `THEORY` | 公式或理想假设 | 否 |
| `SIMULATION` | 根据模型计算 | 否，必须说明假设 |
| `TARGET` | 待验收指标 | 否 |
| `MEASURED` | 仪器、工况、原始数据可追溯 | 是 |

参量阵原理、器件手册和安全资料的统一入口见 [04-开源参考.md](04-开源参考.md)；具体验收方法见 [07-版本阶梯与风险.md](07-版本阶梯与风险.md)。

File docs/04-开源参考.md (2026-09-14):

# 04 · 参考资料、证据等级与复用边界

> 版本：v2.0
> 日期：2026-09-13

本文件说明当前 120 阵元机械转向系统应使用哪些资料，以及哪些结论必须由本机实测产生。它不是购物链接或开源代码收藏夹。

## 1. 证据等级

| 等级 | 资料 | 可支持的结论 |
|---|---|---|
| A | 同行评议论文、政府或国际安全机构资料 | 原理、已知方法、安全背景 |
| B | 芯片制造商数据手册和官方软件文档 | 引脚、电气额定值、API 和外设行为 |
| C | 本项目可复现源码、自动测试和原始测量 | 当前实现、协议一致性和实机性能 |
| D | 开源项目、论坛、博客和商品页 | 实现线索、采购候选和排错思路 |

优先级为 `本项目实测/源码 + 官方资料 > 论文综述 > 第三方实现 > 商品描述`。低等级资料不能覆盖官方额定值，也不能替代本机波形、温升和声场记录。

## 2. 参量阵原理与调制

- [Pompei：The Use of Airborne Ultrasonics for Generating Audible Sound Beams](https://aes.org/publications/elibrary-page/?id=12092)
- [Gan、Yang、Kamakura：A review of parametric acoustic array in air](https://doi.org/10.1016/j.apacoust.2012.04.001)
- [Experimental Evaluation of Distortion in Amplitude Modulation Techniques for Parametric Loudspeakers](https://doi.org/10.3390/app10062070)

这些资料可用于解释空气非线性、自解调、调制失真和测量方法，但不能直接证明本项目已经达到某个声压、失真或覆盖角。

本项目当前实现 DSB-AM 和平方根幅度调制 SRAM。任何“SRAM 一定更清楚”或“失真降低到某个百分比”的结论都必须在相同可听基波声压、相同测点和相同分析带宽下实测。

## 3. 当前硬件资料

### 3.1 TC4428A

- [Microchip TC4428A 产品页](https://www.microchip.com/en-us/product/TC4428A)
- [TC4426A/TC4427A/TC4428A 数据手册](https://ww1.microchip.com/downloads/aemDocuments/documents/APID/ProductDocuments/DataSheets/TC4426A-TC4427A-TC4428A-1.5A-Dual-High-Speed-Power-MOSFET-Drivers-2000142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)

施工前必须从官方手册核对封装、引脚、供电范围、输入门限、输出结构、去耦和热特性。峰值输出电流不能解释为对任意容性负载的连续安全电流。

### 3.2 SN74HC125

- [Texas Instruments SN74HC125 产品页](https://www.ti.com/product/SN74HC125)

当前整机使用 3.3 V 供电的 `SN74HC125N`，不是旧方案中的 5 V `74AHCT125`。器件后缀、封装和厂商不同时，应重新核对引脚和电气参数。

### 3.3 TCT40-16T

- [TCT40-16T/R 通用数据表](https://cdn.sparkfun.com/assets/7/2/0/2/0/TCT40-16-T-R.pdf)

不同卖家和批次可能不是同一制造来源。40 kHz 标称频率、静电电容和灵敏度只能作为抽检起点；120 只阵元应记录批次，并抽测谐振峰、幅值和相位一致性。

## 4. ESP32-S3 官方资料

- [ESP32-S3 Programming Guide](https://docs.espressif.com/projects/esp-idf/en/stable/esp32s3/)
- [LEDC 外设](https://docs.espressif.com/projects/esp-idf/en/stable/esp32s3/api-reference/peripherals/ledc.html)
- [GPTimer 外设](https://docs.espressif.com/projects/esp-idf/en/stable/esp32s3/api-reference/peripherals/gptimer.html)
- [ESP32-S3 数据手册](https://www.espressif.com/sites/default/files/documentation/esp32-s3_datasheet_en.pdf)
- [ESP32-S3-WROOM-1 数据手册](https://www.espressif.com/sites/default/files/documentation/esp32-s3-wroom-1_wroom-1u_datasheet_en.pdf)

这些资料支持外设能力和 API 用法。它们不能单独证明本项目的 40 kHz 更新无毛刺、GPTimer 无跳样或 12 路外部输出严格同相；这些结论仍需自动测试和仪器记录。

## 5. 桌面软件资料

当前桌面实现依赖 PySide6、OpenCV、Ultralytics、PyTorch、sounddevice/PortAudio 和可选 OpenVINO。依赖版本以 `pyproject.toml` 和 `uv.lock` 为准，运行方式以根 README 为准。

第三方库文档可用于确认 API，但项目行为应以以下文件为准：

- `src/vision_gimbal/bootstrap.py`：实际装配关系；
- `configs/vision_gimbal.toml`：当前运行参数；
- `src/vision_gimbal/protocol/`：电脑端协议实现；
- `src/full_size/src/protocol/`：固件端协议实现；
- `tests/`：可重复的软件回归验证。

## 6. 可借鉴但不属于当前方案的项目

- [SonicSurface](https://github.com/upnalab/SonicSurface)
- [Ultraino](https://github.com/asiermarzo/Ultraino)

它们可用于理解声场仿真、相位控制、换能器标定和阵列工具链，但当前项目没有采用其多通道相控硬件。不得直接复制其相位表、阵元坐标、通道映射或安全参数。

以下内容属于未来研究，不得写成当前能力：

- 逐通道相位控制；
- 电子波束转向；
- 有限距离聚焦；
- 三维阵元标定和幅相补偿。

## 7. 安全资料

- [ICNIRP：Airborne Ultrasound](https://www.icnirp.org/en/frequencies/ultrasound/index.html)
- [Health Canada Safety Code 24](https://www.canada.ca/en/health-canada/services/environmental-workplace-health/reports-publications/radiation/guidelines-safe-use-ultrasound-part-industrial-commerci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)

安全资料用于制定保守的测量和暴露控制流程。不能因为 40 kHz 通常听不到，就把设备视为无需管理；也不能使用手机分贝 App 代替具有合适带宽、动态范围和校准记录的仪器。

## 8. 本项目证据

| 结论 | 首选证据 |
|---|---|
| GPIO4 频率、占空比和停止行为 | 示波器原始波形 |
| 12 路同相程度 | 同触发条件下的多路逻辑/示波器记录 |
| 传输稳定性 | STATUS 计数和带时间戳的 JSONL 日志 |
| 电脑端协议字段和行为 | `tests/test_device_protocol.py` |
| 电脑与固件跨语言布局 | 受版本控制的 C++ 测试桩或板上抓包；当前需单独验证 |
| 音频预处理 | 输入/输出 WAV、配置和频谱数据 |
| 方向性 | 固定距离、固定增益的角度扫描原始数据 |
| 可听失真 | 相同声压条件下的录音和频谱/THD 分析 |
| 安全 | 合适仪器在人员耳位的分频带测量和保守操作记录 |

`output/` 和 `work/` 中的本机文件可以用于排错，但若要作为正式证据，必须同时记录固件提交、配置、串口、硬件接线、测量时间和仪器信息，并移入受版本控制的证据目录。

## 9. 引用与复用检查表

引用外部资料前确认：

1. 资料是否直接对应当前器件型号、封装和供电条件；
2. 结论是论文/手册原文、工程推断，还是本项目实测；
3. 第三方项目是否使用了不同阵元、频率、通道数或驱动拓扑；
4. 数字是否带单位、测量条件、日期和来源；
5. 是否把未来功能误写成当前能力；
6. 是否保留了本项目原始数据和复现实验步骤。

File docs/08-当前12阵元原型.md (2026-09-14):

# 08 · 历史档案：4×3、12 阵元原型

> 状态日期：2026-08-13
> 归档日期：2026-09-13
> 状态：已退役，仅用于解释早期台架和实验来源

当前正式整机是 120 阵元单 GPIO + 二维机械云台，见根 [README](../README.md)、[正式固件](../src/full_size/README.md) 和 [当前接线](09-当前120阵元单GPIO接线.md)。本文件中的 GPIO、功率分组、波特率和命令不能用于当前 120 阵元整机。

## 1. 原型目的

该原型用于在正式阵面之前验证：

- ESP32-S3 能生成 40 kHz 载波；
- TC4428A 可以进行互补差分驱动；
- 12 个 TCT40-16T 可以按 4 列 × 3 行装配；
- 简单包络和 Flash PCM 能进入超声发射链；
- 初步建立安全上电、示波器和温升测试方法。

它不能证明已经完成 120 阵元整机、视觉跟踪、经过标定的可听声压或电子聚焦。

## 2. 历史硬件

```text
正面观察

 CH1     CH2     CH3     CH4
  ○       ○       ○       ○
  ○       ○       ○       ○
  ○       ○       ○       ○
GPIO4   GPIO5   GPIO6   GPIO7
```

- 共 12 个换能器；
- 每列 3 个并联；
- 每列使用一个 ESP32 GPIO 和一片 TC4428A；
- 四路可以单独开启或同相开启；
- 串口监视器使用 115200 baud。

当前正式固件已将超声输出收敛为 GPIO4 单通道，并把 GPIO5、GPIO6 用于俯仰和水平舵机，因此旧引脚分配不得复用。

## 3. 历史固件

归档工程位于：

```text
src/esp32_s3_4x3_min_test_deprecated/
```

入口为：

```text
src/esp32_s3_4x3_min_test_deprecated/esp32_s3_4x3_min_test.ino
```

该目录不参与当前 Python 测试，也不应作为新开发起点。若需要复现实验，必须整体使用归档目录及其 README，不能把其中部分文件复制回 `src/full_size`。

## 4. 历史命令差异

| 旧命令 | 历史行为 | 当前状态 |
|---|---|---|
| `1`～`4` | 单独开启四列 | 正式固件已删除 |
| `A` | 四列同相载波 | 当前表示完整 120 阵元载波 |
| `T` | 四列 1 kHz 包络 | 当前表示完整阵列包络测试 |
| `P/L` | 播放归档 Flash 音频 | 当前读取正式固件自己的 PCM |
| `0` | 停止四路切换 | 当前只停止 GPIO4 切换 |

旧字母命令中的部分字符在正式固件中仍存在，但作用对象和串口速率已经变化。

## 5. 历史结论的正确使用

早期手机测试曾显示正前方读数明显高于偏轴位置，但普通手机麦克风和分贝 App 通常不覆盖 40 kHz，且可能受到混叠、自动增益和麦克风非线性影响。

因此历史结论只能写成：

> 12 阵元台架建立了载波、差分驱动和包络实验链路，并观察到疑似超声方向性；该结果不是经过校准的 40 kHz 声压或定向可听声证明。

不得把该原型的手机读数、四路引脚、负载数量或温升外推到当前 120 阵元整机。

## 6. 为什么退役

- 正式阵面改为 120 个换能器；
- 功率结构改为 12 组 × 10 只；
- 超声逻辑改为 GPIO4 经 SN74HC125 扇出 12 路；
- GPIO5/GPIO6 改作二维舵机；
- 串口改为 460800 baud，并增加二进制音频/云台复用协议；
- 电脑端正式实现迁移到 `src/vision_gimbal`。

## 7. 归档规则

- 只修复会妨碍历史复现的严重错误，不为归档固件增加新功能；
- 当前需求、接线和启动说明不得链接到归档目录作为默认入口；
- 若归档代码不再需要随主分支持续携带，可在建立 Git tag 后删除；
- 新测试必须针对 `src/vision_gimbal` 和 `src/full_size`。

## 8. 仍然适用的安全原则

- 换能器接在 TC4428A 两个输出之间，两端都不能接地；
- 示波器两个探头地夹都接公共地，通过数学通道计算差分；
- 软件停止不等于 12 V 断电；
- 从单片、单只负载逐步增加；
- 不把耳朵靠近阵面，不用手机 App 判断超声安全。

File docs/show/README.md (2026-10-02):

# 项目演示文件

- [超声参量阵视觉跟随定向音响-终审答辩.pptx](超声参量阵视觉跟随定向音响-终审答辩.pptx)：比赛终审答辩版，12 页。
- [超声定向音响-开题交流报告.pptx](超声定向音响-开题交流报告.pptx)：项目早期开题记录。

终审版已取代两个初审版文件。Git 历史仍保留旧版，日常展示以终审版为准。

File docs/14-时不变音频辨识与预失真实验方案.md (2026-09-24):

# 时不变音频辨识与预失真实验方案

日期：2026-09-21。状态：实验设计，尚无配对声学测量、拟合结果或已验证补偿器。本文不修改现有播放配置。

## 1. 目标与边界

在固定位置、固定调制和驱动档位、固定输入范围下，辨识一个参数不随时间更新的非线性模型，再离线计算预失真 PCM，使实测声音接近目标。

- 第一版目标频带：250–3000 Hz；这是项目当前的设计工作带宽，最终应根据实测信噪比和可逆性收窄。
- 固件输入：8000 Hz、单声道 PCM_U8，静音码 128。
- 声学采集：独立麦克风，优先 48000 Hz、24 bit PCM；设备只有 16 bit 时亦可先验证。
- 模型拟合、补偿后的主要误差在工作频带内计算；原始 48 kHz 录音保留，用来检查带外失真。
- 固定设置建议 RAW + STANDARD。DSB 和 SRAM 用相同 PCM 做短预实验，再选一个作为主实验模式；不预先假定 SRAM 实测一定更好。
- BOOST 若实际需要，作为独立实验配置重新辨识。不同模式的数据不能不加区分地混合拟合。
- 不建模云台运动、位置变化、温漂过程和自适应参数更新。用重复测量检验这项简化是否成立。

时不变只表示把输入延迟，输出也相应延迟；不表示线性，也不表示没有记忆。固定 FIR 和固定非线性都允许存在。

## 2. 系统边界与当前项目的注意事项

辨识对象：实际发送的 PCM 字节 → 固件调制/驱动 → 换能器/空气/固定位置房间响应 → 麦克风测得的音频。

没有校准麦克风时，输出单位为固定录音增益下的数字幅度，不能称为绝对声压 Pa 或声压级。麦克风频响会成为端到端模型的一部分。

当前代码事实：

1. `configs/vision_gimbal.toml` 的播放设置是 loud、boost=true、dsb_am；模型实验必须显式指定设置。
2. `AudioPreprocessor` 始终串接慢速电平器及压缩限幅器。固件 RAW 不会旁路这些电脑端处理。辨识优先直接发送预先生成的 PCM。
3. `utils/audio_stream_probe.py` 可直接发送头文件中的 PCM 字节、指定 raw/standard/dsb 或 sram，并保存传输日志，可复用为实验发送端。
4. `utils/wav_to_audio_header.py` 的 `convert()` 会逐文件去直流、峰值归一化至约 90%、淡入淡出，且量化比例与实时量化器略有不同。不能直接用该转换流程制作保幅度的多电平实验；可以复用只负责写头文件的 `write_header()`。
5. 内置纯音 `envelope_modulator.cpp` 的 STANDARD 偏置为 0.55，而 PCM `audio_modulator.cpp` 为 0.45；内置纯音也不经过同一套 PCM 调制选择。所有辨识和验收纯音均生成 PCM 并走实际 PCM 播放路径。
6. `PostLimiterWavRecorder` 保存的是发送前的数字监听信号，不是麦克风录到的阵列输出，也不是精确的量化后输入。必须另存实际 PCM 字节并独立录音。

## 3. 第一版模型：线性基线与三阶并联 Hammerstein

先拟合 M1 线性 FIR，再拟合 M2 二阶、M3 三阶模型，用验证集判断增加非线性分支是否值得。

理想结构写成：

\[
\hat y[n]=c+\sum_{p=1}^{P}\sum_{k=0}^{L-1}h_p[k]\phi_p(x)[n-k],\qquad P\in\{1,2,3\}.
\]

其中一阶分支描述线性频响，二阶分支能产生二次谐波及和差频，三阶分支能描述一部分压缩和三阶互调。所有 h 在播放期间固定。

概念上 phi_1=x、phi_2=x²、phi_3=x³。但实现时不能直接在 8 kHz 下对高频输入平方/立方并把混叠当成真实声学失真。例如 2.5 kHz 的二次谐波是 5 kHz，不是 8 kHz 离散平方得到的 3 kHz。

第一版采用固定的过采样特征：

\[
z=U_6(x),\qquad \phi_p(x)=\downarrow_6\{B_{AA}[z^p]\}.
\]

- U_6：固定抗成像插值，将 x 从 8 kHz 重建至 48 kHz；不是简单复制样本。
- B_AA：固定抗混叠低通，通带覆盖 3 kHz，至 4 kHz 前有充分衰减，然后降至 8 kHz。
- 所有分支保存滤波器状态、延迟和边界约定；训练、预测、优化使用完全相同的实现。
- y 也经固定抗混叠滤波降至 8 kHz。评价时再统一选择 250–3000 Hz。
- 48 kHz 插值是基带重建的建模假设，不是 40 kHz PWM 波形仿真。它不保证完整描述真实换能器前置滤波、载波采样效应或 AM–PM 耦合。

推荐起始 P=3、L=128，即每分支 16 ms，共 384 个 FIR 系数加常数项。验证候选 L=64/128/256；脉冲响应有更长尾部时，可增加 L 或改善反射条件。固定房间的长混响不意味着系统时变，但会要求更长记忆。

该结构是简化模型，缺少一般 Volterra 模型中的 x[n-k]x[n-l]（k≠l）等独立项。若新双音预测仍明显错误，先检查对齐、混叠、测量及房间尾部，再考虑少量交叉延迟项或固定前置滤波块；不要直接认定系统一定时变。

## 4. 采集布置与重复性预实验

1. 阵列和麦克风都固定在支架上，关闭云台跟踪。先选实际使用的一个位置，例如轴上约 1 m，记录距离、角度、高度、附近反射面；该距离不是默认满足某个远场条件的声明。
2. 固定载波、供电、RAW、驱动档位、调制方式和录音增益。关掉录音端 AGC、降噪、回声消除和音效。
3. 原始录音不逐段归一化。尽量让最高测试档录音峰值留有约 6 dBFS 余量，同时低档仍具有足够信噪比；这是录音电平余量，不是声压安全阈值。
4. 测量麦克风需能在实际超声场中保持线性。ADC 前已发生的超声整流/过载不能靠录音后低通消除；若对此有疑问，先验证测量链，不把所有谐波都归因于阵列。
5. 先记录关载波的环境底噪，再记录 PCM=128、载波保持开启时的基线。二者不是同一状态。
6. 先低档播放并观察稳定性；首尾重复相同参考信号，中间每约两分钟重复一次。记录设备运行时长、温湿度（可取得时）及供电情况。
7. 若参考信号的频响、电平或失真随实验顺序显著漂移，先延长稳定时间、改善供电或缩短采集批次；不把不同工作状态硬拟合为同一个系统。

## 5. 信号与数据量

峰值候选 A=0.10、0.20、0.40、0.60，均指最终量化前归一化峰值，不是 RMS。由最低档开始；只有测量与设备运行正常才继续提高。若低档接近量化或录音噪声底，标为低置信度或调整档位，不用它强行拟合高阶分支。

量化统一用 q=clip(round(128+128x),0,255)，保存后以 x_actual=(q-128)/128 建模。由于取整，实际峰值需从字节重新计算；补偿器最终约束用允许的整数码范围表示。

| 数据类型 | 第一轮建议 | 用途 |
|---|---|---|
| 底噪/载波基线 | 各 10 s | 信噪比、固定杂音 |
| 对数扫频 | 250–3000 Hz，10 s，4 档，每档 2 次 | 工作带宽、响应趋势、延迟检查 |
| 随机相位多音 | 每段 8 s，12 个独立相位种子 × 4 档 | 主拟合数据，共 48 条 |
| 带限随机噪声 | 每段 8 s，6 个独立种子 × 4 档 | 不同幅度分布/峰均比的补充，共 24 条 |
| 双音 | 5 对 × 3 个有效档，每条有效 2 s，每次含缓入缓出 | 互调与模型泛化 |
| 单音 | 300/400/500/700/1000/1500/2000/2500 Hz，3 档，有效 2 s | 频响与谐波 |
| 自然音频 | 不同来源的语音/音乐 6–10 条，每条约 8 s | 实际内容泛化、补偿验收 |

完整初轮包含同步、间隔和重复约需 20–30 分钟，具体由参考信号与重录次数决定。先用约 2 分钟的小批次验证配对、幅度保持和日志，再录完整批次。

多音使用 1 s 为周期、FFT 整数频点，约 40–80 个覆盖目标频带的频率；相位随机，生成后检查峰均比。按预先指定的 A 整体缩放，不通过削波压低峰值。记录实际峰值、RMS、种子和全部频点。可留空部分频点观察非线性新增能量。不同档位使用同一组种子便于比较。

双音建议：(500,700)、(700,1100)、(900,1400)、(1200,1700)、(1700,2300) Hz。两音等幅，控制合成峰值；记录 f1±f2、2f1、2f2、2f1−f2、2f2−f1 等位置。重合的产物频点只统计一次，并区分噪声与真实谱线。

每条录音包含：0.5 s 载波开启基线 → 固定同步标记 → 0.5 s 间隔 → 有淡入淡出的测试信号 → 0.5 s 间隔 → 相同同步标记 → 0.5 s 尾段。间隔应根据实测衰减加长，避免标记尾声污染有效段。拟合不使用标记和启动瞬态。

## 6. 数据保存和划分

每个 take 保存：

```text
take_0001/
  input_u8.bin            # 实际发送的完整字节，包括标记和间隔
  input.wav               # 与字节完全一致的 8 kHz PCM_U8 WAV
  recorded_48k.wav        # 独立麦克风的完整原始录音
  metadata.json           # 设置、种子、音量、位置、设备、输入哈希
  stream.jsonl            # 传输/设备诊断日志
  alignment.json          # 延迟、时钟比例、有效区间、质量判定
```

metadata 至少包括：take/session ID、时间、信号族/种子、训练划分、采样率、量化公式版本、字节 SHA256、峰值/RMS、raw/standard/dsb 等模式、载波、固件版本、麦克风/声卡型号、录音增益、位置、时长、重复编号、是否为原始或补偿输入。

以完整信号种子/音源划分，建议 train/validation/test≈60/20/20。一个种子的全部音量及重复必须属于同一个集合，不能把相邻采样点或重叠窗口随机分给三个集合。单独保留未参与选模的双音、单音和自然音频作最终验收。另一天同位置重录可作额外稳定性测试。

## 7. 配对、对齐与质量门槛

电脑录音时钟与 ESP32 播放时钟独立。单次互相关只能校正偏移，长录音还要校正时钟比例。

1. 由前后标记在输入/录音中的间隔估计比例，拟合 t_record=a·t_input+b。
2. 使用带抗混叠的重采样校正 a，再通过标记模板或低档参考响应估计整数及分数延迟 b。标记输出会被系统改变，不要依赖原始标记与录音必然高度相似。
3. 对齐参数由标记/独立参考段获得；不能反复扭曲测试主体来降低模型误差。
4. 保存全部校正参数。所有模型用同一对齐；FIR 留出固定因果余量并明确移除的大延迟，避免把相位误差藏在模型外。
5. 先对齐每次重复，再决定是否平均；先平均未对齐录音会抹掉高频相位。
6. 数据分块保留输入历史；块首滤波建立过程不计损失，分块长度应明显大于模型记忆。

有效段必须无录音削波、无实际 PCM 裁剪、无传输间断。检查有效播放时间内 underrun、overrun、CRC、sequence gap、timer skip、host drop 等计数增量；启动/结束阶段单独标记，不能只看最终累计值。时钟比例校正后的中间标记或重复周期仍不对齐时，应重录/检查丢样，不能用一个固定滤波器吸收它。

报告各档信噪比；信号接近噪声底时不报告精确的微小 THD 改善。开头/结尾参考的变化需小于待证明的补偿改善，否则本轮不能支持该结论。

## 8. 最小二乘拟合

给每个 p 的特征构造延迟矩阵 Phi_p，将它们及常数列拼成 Phi。模型是对输入非线性、对待估计系数线性的，因此拟合仍是正则化线性最小二乘。

\[
\theta^*=\arg\min_\theta\sum_j\frac{w_j}{N_j}\|B(\Phi_j\theta-y_j)\|_2^2
+\sum_{p=1}^{P}\lambda_p\|h_p\|_2^2.
\]

B 为固定工作频带滤波器；它同样作用于预测和实测，不能只滤实测。N_j 是有效样本数。各音量档先等权；低信噪比样本按质量降权，不用每条录音各自归一化的方法“平衡”音量。

具体流程：

1. 只用训练集统计各特征的缩放，保留正负和幅值依赖；把同一缩放用于验证/测试。平方特征直流可用一个全训练集固定均值处理，不能逐条重新中心化。
2. 先拟合 P=1 基线，再拟合 P=2/3。
3. 候选 L=64/128/256，标准化后的正则化强度例如从 10^-6 到 1 做对数网格搜索。该数值范围只是起点，与损失归一化约定绑定。
4. 初轮各分支用相同 lambda；高阶分支不稳定时增加其正则化。常数项单独处理，避免与 DC 不可辨识。
5. 小数据可用 QR/SVD 解增广最小二乘；大数据用带正则化的 LSQR/分块算子。公式上的 (PhiᵀPhi+Lambda)^-1 不是要求显式求逆，整段长录音也不应全部展开成巨大稠密矩阵。
6. 依据验证集分档 NMSE、双音预测、自然音频预测选择最小的有效模型；不以训练误差最低作为选型理由。
7. 保存 h、P/L、全部重采样/滤波系数、特征缩放、输出单位与录音增益、对齐约定、工作模式、输入范围、训练哈希和版本。

如果 P=3 对新信号并无稳定改善，保留 P=1 或 P=2。采集设计中的高阶激励也可用于证明简单模型已经足够。

## 9. 从前向模型到预失真

先完成前向预测验证，再设计补偿；模型能拟合训练录音不代表它的逆能改善真实播放。

目标 d 是工作频带内、以同一固定录音幅度标尺表示的目标声压波形。由一个独立参考确定整体转换增益；未校准麦克风时只是相对数字标尺。不能给每个补偿结果分别拟合一个最有利增益来评分。

### 9.1 线性均衡基线

用一阶模型/低档响应 H1 设计有增益限制、带正则化的 FIR 均衡器 G，在模型的已训练输入范围内播放。复数频域起点为 G=H1*/(|H1|²+lambda(f))，实现时保留固定延迟和边界填充。不要对低响应频段硬做 1/H；必要时缩窄目标频带、降低整体目标声级。

### 9.2 第一版非线性补偿：离线优化整段 PCM

\[
x^*=\arg\min_{x\in C}\frac{\|B(F_\theta(x)-d)\|_2^2}{N}
+\alpha\frac{\|x\|_2^2}{N}
+\beta\frac{\|Dx\|_2^2}{N}.
\]

C 限定实际训练过的峰值、输入频带、RMS/峰均比范围；D 是一阶差分。beta 可从 0 开始，仅在需要抑制不必要高频时增加，避免把想保留的高频细节一起抹掉。

- x 初值为线性均衡输出；目标是固定参数系统的非线性最小二乘，不保证全局最优。
- 可用带约束梯度法或 Gauss–Newton。若实现用带限基底 x=Sa，需对重建后的 Sa 施加峰值约束；简单“低通后裁剪”会重新产生带外成分，必须迭代并检查最终约束。
- 固定目标声级。不可达时统一降低本次对照的目标声级，不用饱和输出换取数值误差降低。
- 保留模型记忆和滤波器尾部，短段先做完整离线优化；长段分块需处理历史、重叠和拼接瞬态。
- 优化时可先使用连续幅度；随后按允许整数码范围量化，再把实际量化后的 x_actual 送入模型复核，最后真实播放。
- 超出训练域或模型不确定的解不直接接受；补采该范围或降低目标。
- 8 kHz 带内模型不能证明 3 kHz 以上声学失真也下降，必须用原始 48 kHz 录音另行检查。

alpha/beta/目标声级只用验证内容选择。最终测试内容的目标波形可以送进已锁定的优化器，但其真实输出录音不能再用于调参；否则该内容已变为验证数据，需要另准备最终测试集。

第一版不要同时做实时补偿器。离线端到端有效之后，再研究固定 FIR 或较小固定预失真器的实时实现。

## 10. 测试与验收

### 10.1 前向模型是否成立

所有测试均报告分音量、分信号族结果，而不是只有一个总体平均数。

\[
NMSE=10\log_{10}\frac{\sum_n[B(y-\hat y)]^2}{\sum_n[B y]^2}.
\]

只在有效非静音段计算，越负越好。保留固定增益和相位，不单独缩放预测。另看频响偏差、谐波/互调谱线位置与幅度、残差频谱，以及重复录音之间的误差下限。

建议的初轮内部目标（非已测成绩、非行业标准）：高信噪比测试段 NMSE 约 -15 dB 或更好；非线性模型比线性基线改善至少 3 dB，且改善不是仅来自某一音量。若重复测量本身达不到这一量级，先解决测量稳定性。

### 10.2 真实补偿是否有效

锁定相同 RAW、驱动和调制，比较三组：原始输入、线性均衡、非线性预失真。随机化播放顺序，各录 3 次。

公平比较的目标是相同的可听输出电平，而不是相同输入峰值。纯音匹配基波幅度，语音/音乐用统一工作频带电平准则并报告实测差异；通过独立校准设置播放增益，不靠事后分别缩放录音掩盖差异。

| 指标 | 方法与边界 |
|---|---|
| 目标波形误差 | 对齐后的实测 y 与固定目标 d 计算带内 NMSE；共同目标、共同增益标尺 |
| 频响 | 报告目标频带幅度偏差及平坦度；不能只看一条“更平”的曲线 |
| THD | 稳态单音：sqrt(sum(Ak²,k≥2))/A1；声明统计带宽和可见阶数 |
| IMD | 对无重合的指定组合频点能量求和，除以两基波能量，再开方；列明具体频点 |
| 带外失真 | 48 kHz 原始录音检查 80–250 Hz、3–10 kHz，参考麦克风有效带宽与噪声底 |
| 噪声与电平 | 载波开启基线、录音峰值、实际 PCM 峰值/RMS、量化和传输异常 |
| 听感 | 随机标签、相近响度的 A/B，记录毛刺、沙声、齿音、清晰度 |

THD 测量去除起止瞬态，使用完整周期或窗口及谱线邻域积分。高频纯音谐波可能超出 3 kHz 或分析上限，必须标明；不能把“看不到”当成“没有”。8 bit 输入本身含量化谐波，应保存并分析其频谱，区分输入已有成分与链路新增成分。

建议验收方向：同等可听电平下，多数未见双音/单音的失真比有可重复下降（例如相对降低约 30% 作为初始目标），自然音频目标误差同步下降，且无新增明显带外杂音、削波和传输异常。报告全部频点分布及最差退化项，不只挑改善最大的一项。

## 11. 计划的软件接口（尚未实现）

| 模块 | 输入 | 输出 |
|---|---|---|
| generate | 信号配置、种子、档位 | 精确 PCM、WAV、头文件、清单 |
| acquire | PCM、固定播放配置、录音设备 | 原始录音、发送日志、元数据 |
| align | 配对录音、同步标记 | 时钟比例、延迟、质量判定、有效配对数据 |
| fit | 训练/验证清单、候选参数 | M1/M2/M3、验证报告、冻结的模型配置 |
| predistort | 冻结模型、目标 WAV、约束 | 补偿 PCM、量化后预测与约束报告 |
| evaluate | 测试清单、真实录音、模型 | 分档 NMSE、THD/IMD、带外指标和图表 |

实现已位于 `utils/audio_calibration/calibrate.py`，数据建议存放 `output/audio_calibration/`。它是离线工具，不导入 Qt 主程序、不启动串口也不直接打开麦克风。入口、选项和实验流程见 [15-离线声学校准工具](15-离线声学校准工具.md)。

可复用的现有播放工具调用（头文件必须由保幅度的生成流程准备；COM5 替换为实际端口）：

```powershell
uv run python utils/audio_stream_probe.py --serial-port COM5 --audio-header output/audio_calibration/take_0001.h --processing raw --drive standard --modulation dsb --repeats 1 --log-jsonl output/audio_calibration/take_0001/stream.jsonl
```

此命令只发送和记录传输状态，不负责声学录音。播放前启动独立录音；后续 acquire 模块应统一协调二者。

## 12. 执行顺序与停止条件

1. 保幅度生成和实际 PCM 记录 → 低档短录音 → 检查传输和前后标记。
2. 小规模比较 DSB/SRAM，固定一种模式，确认重复性和可测音量范围。
3. 收集多音、多档、噪声及独立验收内容，冻结数据划分。
4. 拟合 M1/M2/M3，以验证集决定模型复杂度；前向预测不合格则不进入逆优化。
5. 先验证有限增益的线性均衡，再验证非线性离线预失真。
6. 真实重放锁定的测试内容；若只有模型预测改善、真实播放未改善，应判为补偿未验证成功。

## 13. 参考与证据边界

- [Kite、Post、Hamilton：Parametric Array in Air: Distortion Reduction by Preprocessing](https://signal.ece.utexas.edu/members/tom/papers/asa98.html)：支持包络平方的二阶导数近似及换能器带宽对平方根预处理效果的限制。
- [Gudupudi：New insights into loudspeaker nonlinearities](https://www.eurecom.fr/publication/5370)：广义多项式 Hammerstein 作为扬声器非线性辨识结构的背景；并非本阵列的实测验证。
- [Identification of a parametric loudspeaker system using an adaptive Volterra filter](https://doi.org/10.1016/j.apacoust.2012.03.007)：支持参量扬声器非线性辨识及工作条件依赖的背景；本方案不采用在线自适应参数更新。

本方案的数据量、参数搜索范围和验收阈值是针对当前项目的初始工程设计，需由真实测量修订，不是文献给出的性能保证。

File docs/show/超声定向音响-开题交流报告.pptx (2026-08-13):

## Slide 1

超声参量阵定向音响

开题交流报告 · 2026

用超声阵列
把声音送向指定方向

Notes: 各位老师好，我们计划做一台低成本的超声参量阵定向音响。目标不是把声音做得特别响，而是验证声音能否主要送向指定方向，并把方向性、旁瓣和稳定性测出来。

[Sources]
- 项目总览 README.md，第1—2节

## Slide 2

音频决定“播什么”，相位决定“传向哪里”

输入与定位

实时调制与相位

阵列发射与空气解调

电脑端
选择音频或人脸目标
USB发送PCM与坐标

ESP32-S3
生成40 kHz调幅载波
8路载波相位独立

驱动＋96阵元
TC4428差分驱动
空气非线性还原可听声

2

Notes: 系统分三段。电脑负责音频和可选的人脸定位；ESP32把音频包络调制到四十千赫载波，并为八个通道设置不同相位；TC4428驱动九十六个换能器。所有换能器都围绕四十千赫工作，但音频形成载波两侧的边带，空气的非线性差频把它还原成可听声。因此，各通道共享同一段声音，只用相位控制声束位置。

问答准备
- 问：声音怎么从40 kHz变成人耳可听？答：调制产生边带，空气非线性产生差频，不需要接收器。
- 问：播放音频必须烧进板子吗？答：保底版内置，完整版通过USB实时传PCM。

[Sources]
- 01-原理与公式.md，第2—4节
- 02-系统方案与硬件.md，第1节
- 03-软件架构.md，第1节

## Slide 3

先把声音做出来，再增加追踪与聚焦

保底版｜固定定向
96个换能器
8路同相驱动
内置测试音/语音
完成第一张实测方向图

完整版｜8通道相控
USB实时音频
手动转向/焦区
电脑端点击人脸
用热力图验证峰值移动

进阶版｜16通道校准
每列独立驱动
逐通道幅相标定
可选深度传感/云台
以实测改善决定是否升级

3

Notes: 项目按三层推进。保底版只要求固定正前方定向发声，它不依赖电脑、摄像头或FPGA；完整版才加入八路相位、USB音频和电脑端人脸选择，并用实测热力图验证转向与有限尺寸焦区；如果八路结果证明有价值，再升级十六通道和逐列校准。这样视觉和声学链路解耦，任何上层功能失败都不影响保底成果。

问答准备
- 问：8通道能不能任意三维聚焦？答：不能独立控制高度，只验证水平转向与x-z有限焦区。
- 问：为什么不用FPGA？答：当前只做8路，ESP32候选实现先经示波器验证；FPGA不是保底版必要条件。

[Sources]
- README.md，第3节
- 03-软件架构.md，第2节
- 07-版本阶梯与风险.md，第1节

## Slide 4

保底版把握较高，完整版取决于实测标定

判断
现有ESP32-S3、成熟驱动芯片和模块化阵面可以完成原型；真正的不确定性是声压、旁瓣和语音质量。

1→6→12

逐级上电
先验证波形、温升和空气解调

−3 / −10 dB

扫描声场
同时报告主瓣、旁瓣和栅瓣

10–15 min

稳定性测试
默认静音，异常时立即断电

4

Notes: 综合判断，保底版可行性较高，因为器件和链路都成熟，而且可以从单换能器逐步扩到十二个再到全阵。完整版的最大风险不是视觉识别，而是八通道子阵间距造成的栅瓣，以及换能器窄带带来的音质限制。因此我们不预报主瓣宽度或声压，而是扫描负三和负十分贝区域，记录旁瓣、温升与连续运行结果。最终以实测数据决定是否升级。

问答准备
- 问：定点是不是只有一个点有声？答：不是，是有限尺寸焦区，且会有旁瓣和房间反射。
- 问：视觉识别能否部署在ESP32？答：完整版本采用电脑端更稳，ESP32只接收目标坐标；视觉失败可回退手动。
- 问：安全怎么保证？答：低功率逐级测试、默认/故障静音、保险丝与实体总开关，并进行超声测量。

[Sources]
- README.md，第2—3节
- 07-版本阶梯与风险.md，第1、3、4节

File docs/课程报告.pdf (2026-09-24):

超声参量阵定向音响 / 课程报告 | 第一部分 · 1/3

# 项目目标与声学原理

作者：曹烜赫（caoxhe / Xuanhe Cao） | 报告日期：2026年9月20日

### 1.1 项目目标与整体方案

本项目面向向指定方向传递声音的场景，将可听音频调制到约40 kHz的超声载波上，利用同相换能器阵列的 方向性和空气中的非线性作用产生可听声，再通过摄像头和二维云台使阵面朝向选定的人体。系统把音频处理、 实时传输、嵌入式调制和视觉控制组合为一个可交互的软件与硬件整体。

当前实施版本采用120个TCT40-16T换能器、12路TC4428功率驱动和GPIO4单相位扇出。所有阵元接收相同 的调制波形，声束方向随整个阵面的水平和俯仰角改变；当前未实现逐阵元电子相控转向或距离维度的定点聚 焦。

音频链：音源 → 电脑DSP → 串口PCM → ESP32调制 → 超声阵列

控制链：摄像头 → 人体检测与跟踪 → PI控制 → 二维机械云台

### 1.2 参量阵与空气自解调

设发射信号为 E(t)·sin(2πf_c t)，其中E(t)为随音频变化的包络。在Berktay远场近似适用的条件下，可听声压 与包络平方的二阶时间导数成正比，即 p_audio(t) ∝ d²[E²(t)]/dt²。这说明声音恢复并非简单“取出包络” ：包络的非线性项会产生失真，二阶导数还会改变不同音频频率的相对幅度。

以普通调幅E(t)=b+d·s(t)为例，E²=b²+2bd·s+d²·s²。求二阶导数后，可听输出包含与s″成正比的目标项，以 及与(s²)″成正比的失真项。单频输入的平方项包含二倍频成分。因此，降低失真需要结合包络设计、信号电平 控制与实测校正，不能只提高调制度。

### 1.3 方向性来自短波长与有限口径

取声速343 m/s，40 kHz对应的波长约8.6 mm。仓库记载的阵面口径约23 cm，远大于超声波长，同相叠加 因而有利于形成窄主瓣。若用理想均匀圆口径估算，第一零点半角约为1.22λ/D≈0.046 rad≈2.6°。此值只是 超声理想口径的数量级估算，不等于实测可听声束宽度。

实际方向图还受阵元间距、幅相误差、单元方向性及房间反射影响。项目中的相对声场显示也依赖模型假设， 不能据此宣称已测得声压、传播距离或旁瓣抑制指标。报告采用当前代码与文档说明实现，并保留理论、仿真 与实验结果之间的区别。

依据：README.md；docs/01-原理与公式.md；docs/09-当前120阵元单GPIO接线.md。版本基线：本地HEAD 7d1f352。

曹烜赫 / 软件部分 | 1 / 6

# 音频处理、通信与嵌入式实现

从数字基带到40 kHz超声输出的完整数据路径

### 2.1 电脑端流式音频处理

电脑端支持麦克风、立体声混音和Windows WASAPI进程回环。默认回环音源以48 kHz采集，每10 ms输出 一块数据；物理扬声器静音时，数字回环仍可获取其他程序的播放内容。采集结果合并为单声道，经250 Hz 高通和约3 kHz抗混叠低通后，有状态地重采样到8 kHz。

后续慢速电平调节、动态压缩和限幅用于控制音量与峰值，再量化为无符号8-bit PCM，静音码为128。滤波 器和重采样器跨块保存状态，以避免块边界造成不连续。当前配置未启用实测均衡；理论上的逆频率平方补偿 不能直接当作已标定的整机校正。

### 2.2 单串口复用与缓冲控制

音频和云台共享一个SerialDeviceLink，以460800 baud、8N1发送二进制帧。每个音频包含160个样本，对 应20 ms；帧携带会话标识、序号和样本位置，使用COBS定界及CRC-16/CCITT-FALSE校验。可靠控制命令 按顺序等待ACK，音频帧不重传，以免补发旧声音继续积累延迟。

ESP32使用2048样本环形缓冲，并在收到960样本、即120 ms预缓冲后启动播放。按当前采样格式，原始 PCM负载为8000字节/秒；串口8N1理论承载为46080字节/秒，预留容量可容纳帧开销与控制消息。带宽充 足仍不能消除操作系统调度停顿，因此系统还通过水位反馈和不超过±500 ppm的采样率微调补偿时钟漂移。

### 2.3 包络调制与PWM映射

归一化：s = (sample - 128) / 128

DSB-AM：E = b + d·s；SRAM：E = √[(b+d)·(b+d·s)]

占空比：D = asin(E) / π；duty = round(1024·D)

SRAM在此指平方根幅度调制。其包络平方在理想模型下与输入呈仿射关系，有助于减小平方项带来的失真； 实际效果仍需比较测量。固件按8-bit样本建立查找表，将包络转换为占空比。LEDC以10-bit分辨率生成默认 40 kHz载波，最大占空比为50%，并通过hpoint=(1024-duty)/2保持脉冲近似中心对齐。

### 2.4 定时、输出与故障处理

GPTimer提供8 kHz节拍，即每125 μs更新一个音频样本，约覆盖5个载波周期。GPIO4经SN74HC125扇出 至12片TC4428，每片驱动10只并联换能器。固件提供Flash播放、测试音及实时流入口；缓冲欠载时停止 PWM并回到预缓冲状态。当前任务式更新未与载波边界硬件锁存，仍需关注调度抖动。软件静音停止切换， 但不等于切断12 V功率电源。

依据：src/full_size/README.md；docs/12-实时麦克风与音频流协议.md；audio/preprocessor.py；modulation_math.h及sram_modulator.cpp。

# 视觉跟踪、交互与系统集成

将识别结果转化为稳定、可操作的定向控制

### 3.1 人体检测、身份维持与目标锁定

视觉流水线使用YOLO进行人体检测，再由ByteTrack维持人物轨迹ID，并对不同ID分别进行Kalman平滑与 短时预测。当前配置指向yolo26s.pt，历史提交中的yolo26m属于迭代过程。重复框过滤用于减少重叠检测 带来的显示和选人歧义；用户点击人体框后，还需明确开始追踪，才会激活自动闭环。

目标锁定以用户选中的ID为依据，目标短时遮挡时允许受限预测，丢失超时后释放目标，避免直接跳到另一 个人。默认预测超时为0.20 s、释放超时为0.80 s。近距离时，人体框可能被画面边缘截断，系统根据框高占 比、边界接触和连续确认帧数切换至上半身瞄准点，位置约为框高的30%；退出采用不同阈值，以减少来回 切换。

### 3.2 从图像偏差到云台动作

相机投影模块先根据画面尺寸和视场角估算焦距，再将目标瞄准点相对画面中心的像素偏差转换为角误差： e_x=atan2(Δx,f_x)，俯仰方向同理。两轴控制器将角误差转换为角速度请求，再由统一运动限制器生成连续 的目标角度。

控制请求：ω = Kp·e + Ki·∫e dt + Kd·de/dt

当前两轴：Kp=1.0，Ki=0.08，Kd=0，因此实际按PI运行

控制节拍：10 Hz；死区：0.6°；另有限速、限加速度和软限位

控制器通过积分限幅和输出饱和判断抑制积分累积，并在死区内衰减积分。自动控制与W/A/S/D手动控制先 经过仲裁，统一由ControlService发布指令，避免两个控制源争用云台。当前俯仰软件范围为-25°至75°，小 于固件接收的±90°逻辑范围；装机后的方向、零位及机械边界仍需要对应标定。

### 3.3 桌面端交互与运行可观测性

PySide6界面集中提供画面、选人、开始/停止追踪、目标切换、音源与调制模式选择。界面区分待选目标和 实际跟踪目标，窗口失焦会释放方向键。音频链提供限幅后的PCM16 WAV录音抽头和后台增量STFT频谱， 帮助检查发送前的数字信号；频谱以dBFS表示，不代表空气中声压级或40 kHz超声频谱。

### 3.4 集成方式与现阶段边界

系统按领域模型、应用服务、硬件接口和UI分层，由bootstrap统一装配。视觉、音频及串口工作从界面交互 中分离；未连接设备时可运行视觉与云台控制仿真。可选深度/声场分支只做显示，当前默认关闭。仓库测试 覆盖协议、DSP、控制和UI逻辑，但声学方向性、失真、连续运行稳定性仍须结合真机与仪器验收，不能由软 件测试替代。

依据：docs/11-视觉云台跟踪系统.md；configs/vision_gimbal.toml；control/axis_pid.py、camera_projection.py、close_range_aim.py；tests/。

超声参量阵定向音响 / 课程报告 | 第二部分 · 1/3

# 我的贡献：软件基础与视觉控制

曹烜赫 / caoxhe / Xuanhe Cao | 以本地提交及代码改动追溯个人工作

我主要负责本项目的软件部分，涵盖固件演进、视觉跟踪、桌面交互及实时音频链。按同一邮箱 caoxh25@mails.tsinghua.edu.cn归并身份，在当前HEAD可达历史中，我有39次提交，其中31次非合并提交、 8次合并提交；全仓库为57次提交、48次非合并提交。具体贡献以功能和对应代码改动为依据。

### 4.1 建立软件结构并推进正式固件

我在cbf83f0（8月13日）整理docs、src和utils，在bc759bf与15af2ea中加入并扩展WAV时频分析及批处理； 8月14日通过e3eaffc重构代码，并在afb7666中引入系统定时、调整调度与积压处理。9月1日的96da6fb新增 full_size正式工程，将早期原型中的音频、驱动和调制组织为适配120阵元单GPIO方案的入口，同时用39cc5d0 补充数据流说明。

### 4.2 将视觉识别推进为可控制的跟踪系统

我在fc1aa37、bd53cbf、a119d7a中依次加入YOLO测试、逐人物跟踪与Kalman平滑、GPU支持，随后以 7d7a8e1建立跟踪系统，并通过3d162e0加入上半身瞄准策略。贡献重点是把检测框转换成持续的目标状态和云 台控制请求，处理抖动、短时遮挡及近距离截断等情况，而非仅运行模型输出检测结果。

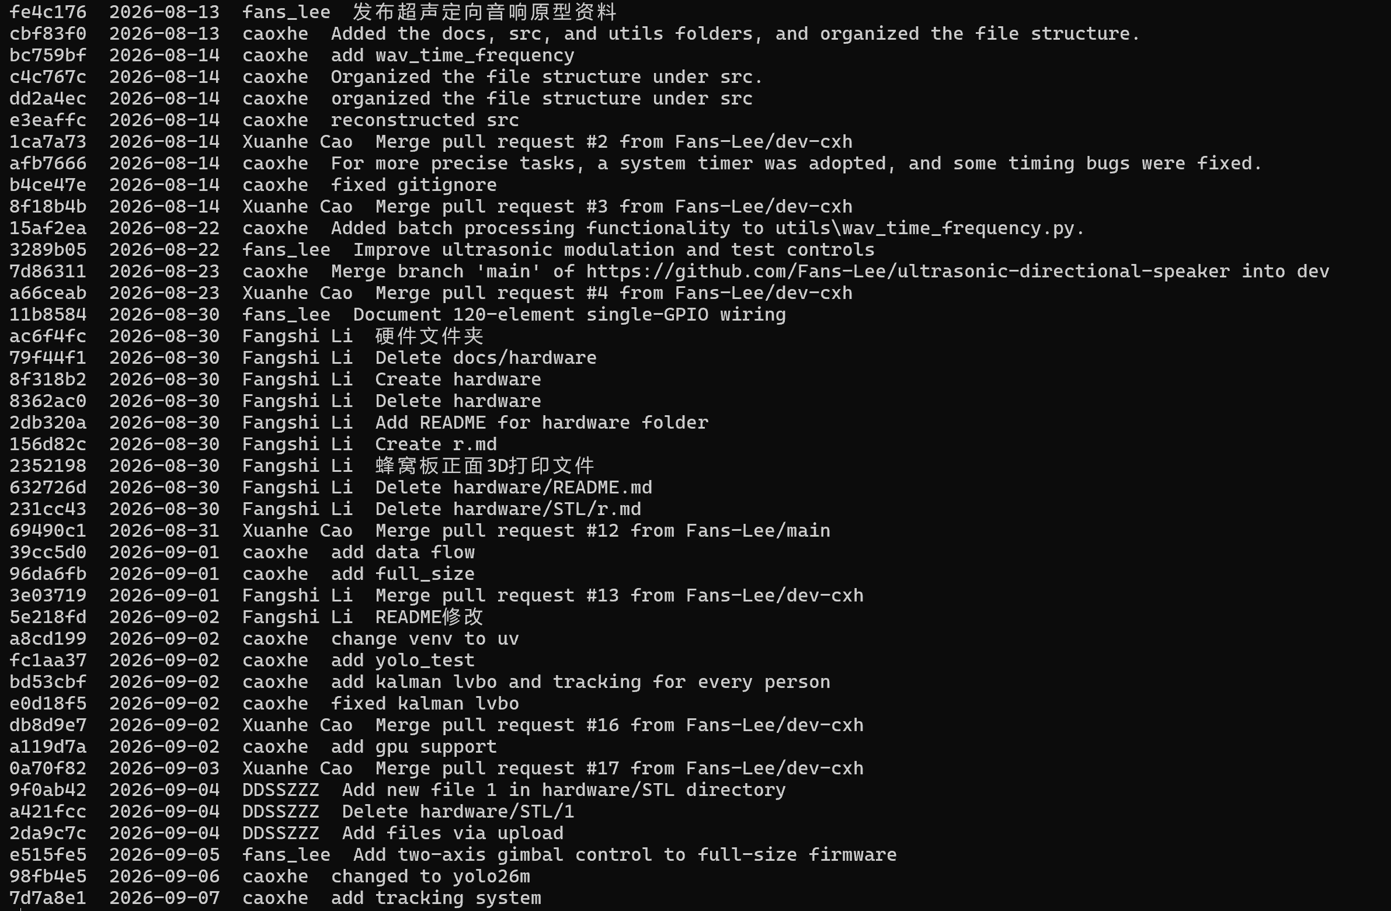
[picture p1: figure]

图1 gitlog-1.png原始截图：早期软件整理、定时改进、正式固件与视觉开发记录。整图保留，可放大核对提交哈希。

协作边界：原型、部分调制及舵机驱动也有队友贡献，如fans_lee的3289b05、e515fe5；我在此基础上推进软件重构、 上位机闭环和集成。

统计口径：git log / git rev-list，范围为HEAD 7d1f352全部可达历史；按作者邮箱识别本人，合并提交单列，不按代码行数估算个人工作量。

# 我的贡献：交互与实时音频链

把单项算法和固件能力组织为可操作、可诊断的整机软件

### 5.1 桌面界面与控制流程

我通过384a988和a5b7ae1（9月7日）逐步完成桌面UI，将视觉画面、目标选择、自动/手动控制及状态反馈 放入统一界面，并补充UI运行测试。随后在8728f12和8811ed6中调整角度与速度参数。该部分不仅是界面 绘制，还包含选中与生效状态的区分、控制权仲裁和运动约束，使用户操作能够对应明确的设备行为。

### 5.2 实时音频DSP与双端协议集成

dd59abf（9月8日）是我的关键集成提交：它新增电脑端AudioService、滤波/重采样/电平处理模块、协议 编解码和唯一串口链路，也新增ESP32音频源抽象、实时环形缓冲及协议服务器。其核心是打通“采集→处理 →分包→传输→缓冲→调制”的双端闭环，并让云台与音频复用一个串口，避免不同服务竞争COM口。

协议设计把可靠控制命令与连续音频区别处理：前者等待ACK，后者用样本序号与状态计数暴露丢失，避免 重传旧帧扩大延迟。电脑DSP保存跨块状态，设备端用预缓冲抵抗调度抖动；两者共同解决持续流运行中时间 连续性的问题。仓库内对应测试覆盖碎片化帧、CRC拒绝、启动确认及采样块数量等边界。

### 5.3 录音、频谱与静音无关音源

我在096a6cd（9月10日）加入处理后录音，在eec8601（9月11日）加入实时频谱，使音频链可以从波形文 件与频谱两侧排查。93aa1d8（9月13日）新增原生WASAPI辅助程序及Python适配层，支持不受物理扬声 器静音影响的系统音频采集，并同步调整UI、配置和测试。其价值是让电脑本地扬声器与超声阵列的播放路 径可以分开控制。

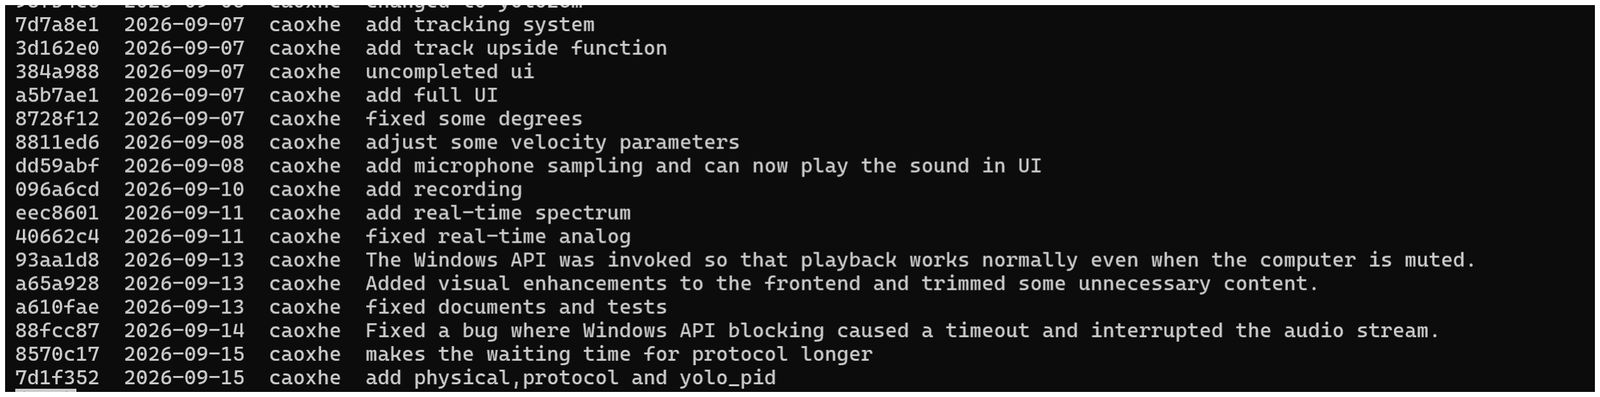
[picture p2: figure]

图2 gitlog-2.png原始截图：UI、实时采集、录音、频谱、Windows回环及后续稳定性修复的连续记录。

为避免“界面可点击但数据链未就绪”，软件将音源生命周期、设备启动ACK和流发送状态关联起来；切换音源 或调制参数时先停止旧流，再建立新流。相应实现位于application/audio_service.py、 infrastructure/serial_device_link.py及两端protocol目录。

提交依据：384a988、a5b7ae1、8728f12、8811ed6、dd59abf、096a6cd、eec8601、93aa1d8；代码与对应测试已在本地核对。

# 我的贡献：稳定性、验证与总结

以问题定位和可追溯交付完善软件工程闭环

### 6.1 修复运行故障并补齐验证路径

针对Windows API阻塞引起的超时断流，我在88fcc87（9月14日）中修改原生回环、Python采集适配器、 AudioService和固件恢复逻辑，加入管道停滞检测、辅助进程重启及流恢复机制，并补充异常退出和停滞场景测 试。8570c17进一步将预缓冲从60 ms提高至120 ms，同时默认关闭可选声场分析，以减轻资源竞争；这一取舍 增加启动等待，用于吸收有限的主机调度停顿。

我在a610fae中统一当前实施基线的文档与测试，7d1f352补充物理原理、协议和视觉控制说明。仓库中的 audio_stream_probe工具支持使用相同PCM字节与调制模式比较Flash和串口路径，使定位问题时能区分信号处 理、链路传输及设备调度。报告核对了代码和测试用例，但不将测试文件的存在写成此次全部测试通过或真机验 收结论。

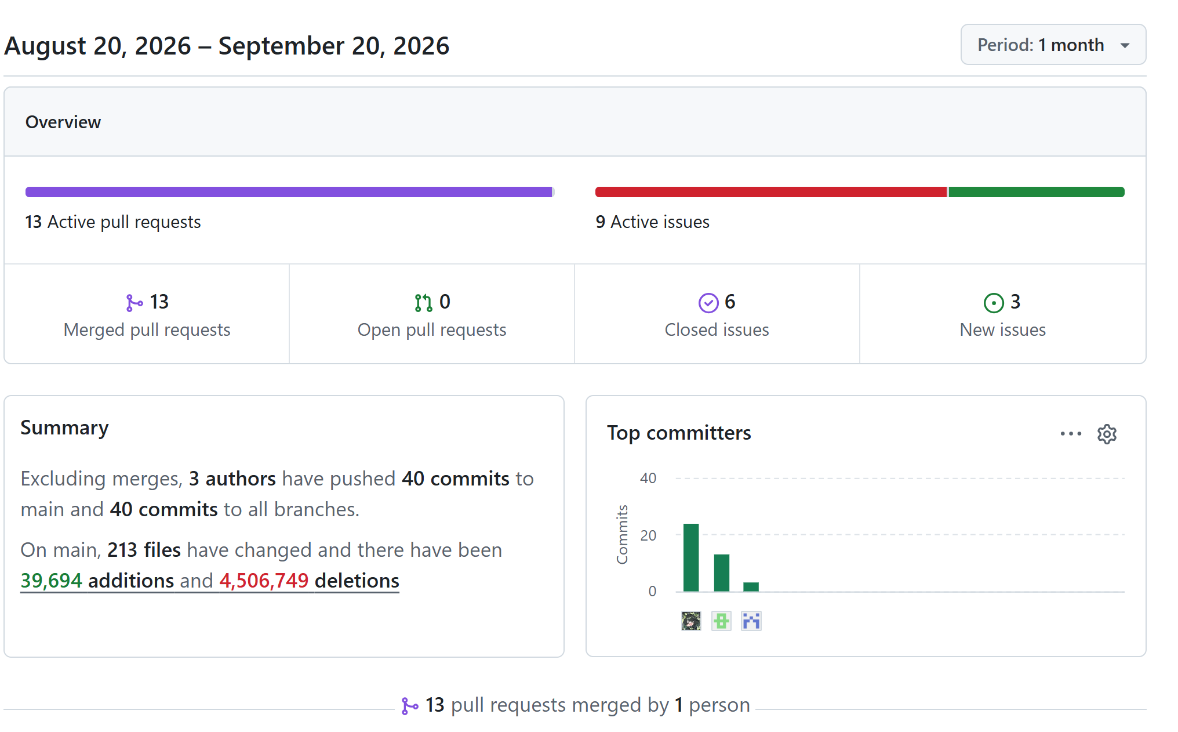
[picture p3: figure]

图3 githuboverview.png原始截图：2026年8月20日至9月20日的仓库活动总览，用于说明团队协作背景。

### 6.2 证据解释与个人收获

图3显示该时间窗内有3位作者、40次非合并提交及13个已合并PR；这些均为仓库整体统计，不能全部归于我，也不 能与全历史的个人计数直接相除。图1、图2中的作者名、日期和哈希，以及本地相应文件差异，才构成个人贡献的 主要证据。大体量音频数据和生成文件也会放大行数，故本报告不把增删行数当作贡献比例。

通过本项目，我将数字信号处理、视觉状态估计、实时通信与嵌入式调度连接成完整的软件系统。主要贡献是建立 并持续完善软件链路，尤其是跨模块接口、可操作的交互流程和故障恢复。后续应在固定工况下记录端到端延迟、 跟踪误差、声束方向图及失真，以可复现实测进一步评价整机效果。

资料入口：github.com/Fans-Lee/ultrasonic-directional-speaker；本地Git截至7d1f352（2026-09-15）。图1至图3均来自docs/assets原图；项目 原理与实现依据本仓库文档、配置及源码，未使用未核实的在线性能数据。

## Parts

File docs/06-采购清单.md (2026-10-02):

# 06 · 120 阵元整机采购、备件与到货验收

> 版本：v2.1
> 日期：2026-10-02
> 本文件给出整机需用量和建议备件，不代表当前库存

采购前先盘点实物。型号、封装、卖家、批次、单价和到货测试必须另行登记；不要把本表的“建议采购量”写成“已经拥有”。

## 1. 核心器件

| 器件 | 当前整机需用 | 建议准备 | 说明 |
|---|---:|---:|---|
| TCT40-16T 发射换能器 | 120 | 130～140 | 留出抽测、离群和焊接损坏备件 |
| TC4428AEPA、DIP-8 | 12 | 14～16 | 每组 10 只换能器使用 1 片 |
| DIP-8 插座 | 12 | 14～16 | 便于逐片测试和更换 |
| SN74HC125N、DIP-14 | 4 | 5～6 | 3.3 V 两级 1→12 扇出 |
| DIP-14 插座 | 4 | 5～6 | 与缓冲器封装匹配 |
| ESP32-S3-WROOM-1-N16R8 开发板 | 1 | 2 | 主控和备件 |
| MG996R 舵机 | 2 | 3 | 水平、俯仰和一个备件 |
| UVC USB 摄像头 | 1 | 1 | 固定焦距、稳定输出目标分辨率 |

`74AHCT125`、多路电子相控后端和 96 阵元专用线束不属于当前采购基线。当前负载匹配依靠 120 只换能器的 40 kHz 复阻抗实测和分组，不因此额外增加固定规格的配组元件。

## 2. 电阻

| 型号 | 最低数量 | 建议数量 | 用途 |
|---|---:|---:|---|
| 10 Ω、1/4 W | 1 | 5 | GPIO4 进入 U0 前串联及备件 |
| 10 kΩ、1/4 W | 13 | 20 | GPIO4 下拉 1 个、12 路功放输入下拉 |
| 47 Ω、1/4 W | 12 | 20 | U1～U3 输出到 TC4428 输入 |
| 4.7 Ω、2 W | 12 | 16 | 每组换能器输出阻尼 |

输出阻尼电阻的阻值和功率最终以波形和温升验证为准。不能在满阵运行时直接短接旁路。

## 3. 电容

| 型号 | 最低数量 | 建议数量 | 用途 |
|---|---:|---:|---|
| 100 nF 陶瓷 | 16 | 20～24 | 4 片 SN74HC125、12 片 TC4428 和入口备用 |
| 10 µF、≥25 V | 12 | 16 | 每片 TC4428 近端储能 |
| 470 µF、≥25 V | 3 | 4 | 三条 12 V 功率分支 |
| 1000 µF、≥25 V | 1 | 2 | 12 V 总入口 |
| 3.3 V 入口储能电容 | 1 | 2 | 缓冲逻辑入口，按施工图选值 |

每片芯片旁边的 100 nF 和 10 µF 不能由总入口大电容替代。电解电容采购和安装时核对耐压与极性。

## 4. 电源与保护

| 项目 | 数量 | 要求 |
|---|---:|---|
| 12 V / 5 A 稳压适配器 | 1 | 中心正，来源和额定值明确 |
| 12 V 总开关 | 1 | 可在不触碰线路时快速断电 |
| 总保险丝和保险丝座 | 1 套 | 额定值按实测工作电流和导线能力选择 |
| 三条功率分支保护 | 3 套 | 便于隔离 P1～P4、P5～P8、P9～P12 |
| 舵机 5～6 V 大电流电源 | 1 | 不使用 ESP32 3.3 V 或 USB 供电 |
| 接线端子和防反插连接器 | 按结构 | 逻辑、12 V、舵机电源分开 |
| 应急断电标识 | 1 套 | 明确哪一个开关切断 12 V |

不要仅按适配器“5 A”标签选保险丝。先从单通道和少量负载测量实际电流，再在导线、连接器、开关和保险丝额定值之间留出合理余量。

## 5. 线材与结构耗材

| 项目 | 建议 |
|---|---|
| 12 V/GND 外部活动主线 | 18 AWG 柔软硅胶线 |
| 板内功率分支 | 18～20 AWG 铜线 |
| 单片驱动和换能器组 | 20～22 AWG 短线 |
| 3.3 V、GPIO4 和控制线 | 24～26 AWG |
| 舵机活动线束 | 满足峰值电流，使用应力释放和弯曲余量 |
| 洞洞板 | 双面独立焊盘，尺寸覆盖 12 路驱动和配电 |
| 阵面材料 | 能承受 120 个换能器重量且不明显弯曲 |
| 紧固件 | 防松螺母、垫片、铜柱和绝缘隔离件 |
| 标识 | 热缩管、号码管或耐久标签 |

活动线束必须在云台全范围内测试，不得拉扯 USB、缠绕转轴或进入齿轮/连杆区域。

## 6. 测量和装配工具

| 工具 | 用途 | 最低要求 |
|---|---|---|
| 数字万用表 | 短路、极性、电压和静态电流 | 可可靠测量 3.3/5/12 V |
| 双通道示波器 | GPIO、TC4428 单端和差分数学通道 | 带宽和探头足以观察 40 kHz 边沿 |
| 逻辑分析仪 | 同时比较 12 路缓冲输出 | 通道不足时分组测并保留同一参考通道 |
| 阻抗测量仪/传递函数测量链 | 逐只测量 40 kHz 处 `R + jX` | 频率、激励幅值和夹具校准条件一致 |
| 限流实验电源 | 单片和单组初测 | 有电压、电流显示和限流 |
| 温度测量 | TC4428、电阻和换能器温升 | 热电偶或经过确认的测温工具 |
| 40 kHz 接收换能器/测量链 | 检查载波和方向性 | 频响、前端线性和带宽已知 |
| 可听频段测量麦克风 | 频响、方向图和失真 | 关闭 AGC，保存原始 PCM |
| 焊接与返修工具 | 批量装配 | 恒温烙铁、助焊剂、吸锡和清洗用品 |

手机麦克风和分贝 App 只能做界面或定性观察，不能作为 40 kHz 声压、安全或正式方向图仪器。

## 7. 到货验收

### 7.1 TCT40-16T

1. 记录卖家、批次、外观标记和到货数量。
2. 检查壳体、引脚、焊盘和尺寸一致性。
3. 对全部 120 只统一测量 40 kHz 处的 `R + jX`，保存原始数据和测量条件。
4. 根据复阻抗计算 12 组并联等效负载，容性与感性单元混合分组。
5. 建立机械极性标记，并验证同相规则。
6. 将明显离群件隔离，不混入正式阵面。

### 7.2 TC4428A 与 SN74HC125

1. 核对完整型号、制造商、封装和顶标。
2. 先在插座和限流条件下测试单片。
3. 检查静态电流、输入门限、输出幅值和空载温升。
4. TC4428A 验证两个输出互补；SN74HC125 验证 `OE` 行为。
5. 通过后才批量复制到 12 路。

### 7.3 电源、开关和连接器

1. 空载检查输出电压和极性。
2. 逐级带载检查压降、纹波和温升。
3. 验证开关确实切断 12 V，而不只是切断控制信号。
4. 进行拉力、应力释放和防反插检查。

## 8. 采购门禁

以下条件未满足前不要执行对应采购或批量装配：

| 动作 | 前置条件 |
|---|---|
| 焊 120 阵元 | 完成 40 kHz 复阻抗测量和 12 组分配，阵面孔位试装、极性规则和单组测试通过 |
| 复制 12 片驱动 | 单片无负载、单只和 10 只测试通过 |
| 固定云台结构 | 实测重量、重心、孔位、扭矩和线束余量明确 |
| 改阻尼或提高 BOOST 时长 | 已有波形、电流和温升对照 |
| 更改配组或外加谐振元件 | 重新测量 40 kHz 等效阻抗、支路电流、波形和温升并单独评审 |
| 采购电子相控器件 | 已建立独立未来项目，不影响当前主线 |

## 9. 库存登记模板

| 日期 | 类别 | 完整型号 | 厂商/店铺 | 批次 | 到货 | 合格 | 已用 | 余量 | 测试记录 |
|---|---|---|---|---|---:|---:|---:|---:|---|
| YYYY-MM-DD | 换能器 | TCT40-16T |  |  |  |  |  |  |  |
| YYYY-MM-DD | 驱动 | TC4428AEPA |  |  |  |  |  |  |  |
| YYYY-MM-DD | 缓冲 | SN74HC125N |  |  |  |  |  |  |  |

采购记录应保存商品页或数据表快照，但商品描述不能代替到货抽测和官方额定值。

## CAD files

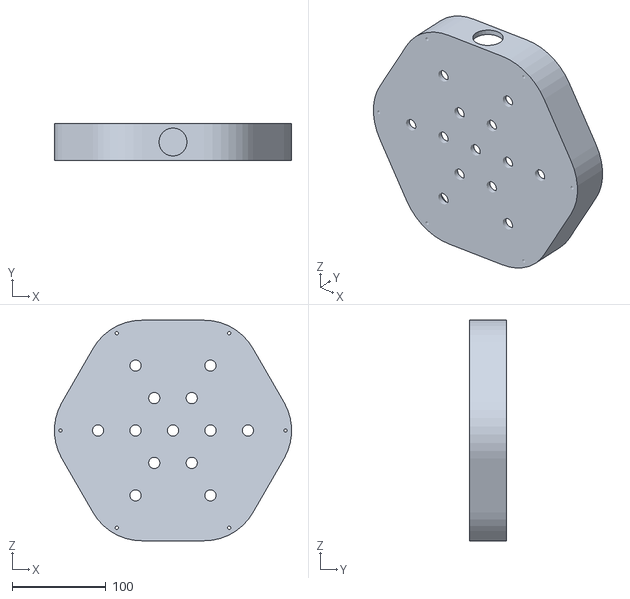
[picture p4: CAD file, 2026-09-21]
hardware/STL/蜂窝背板.STL
253.1 x 40.0 x 235.6

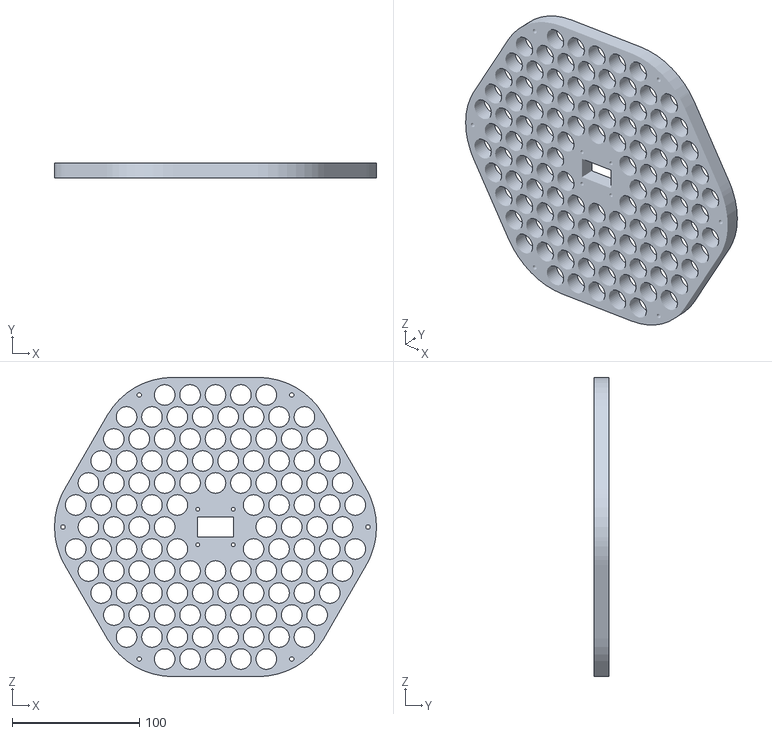
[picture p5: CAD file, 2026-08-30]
hardware/STL/蜂窝阵面前.STL
253.4 x 12.0 x 235.6

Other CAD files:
hardware/STL/base.blend

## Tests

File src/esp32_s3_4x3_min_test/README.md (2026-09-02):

# ESP32-S3 + 12 只 TCT40-16T：4×3 最小测试版

## 固件目录结构

```text
esp32_s3_4x3_min_test/
├─ esp32_s3_4x3_min_test.ino   Arduino 启动入口
├─ README.md                    接线、烧录和测试说明
└─ src/                         Arduino 自动递归编译目录
   ├─ app/                      串口、队列和 FreeRTOS 调度
   ├─ driver/                   GPIO 与 LEDC 硬件驱动
   ├─ modulation/               包络、DSB-AM、SRAM 和音频调制
   └─ data/                     固件内置音频数据
```

主 `.ino` 只负责启动；业务源码放在内层 `src`，以符合 Arduino sketch 对递归编译目录的约定。

## 1. 分组结论

把洞洞板的长边横放，形成 4 列、3 行：

```text
正面观察阵面

 CH1    CH2    CH3    CH4
  ○      ○      ○      ○
  ○      ○      ○      ○
  ○      ○      ○      ○
```

每一列 3 只并联，由一个 LEDC 输出通道和一个 TC4428A 驱动。因此是 **4 个 LEDC 输出通道，每个控制 3 只**。严格说并不是 4 个独立的 LEDC 外设：代码让 4 个输出通道共用 LEDC Timer 0，频率基准相同。

这样做的原因：

- 每个驱动器只承担 3 只换能器的并联电容，比 5 只更轻；
- 有 4 个横向相位自由度，后续可以做左右转向；
- 3 路各带 4 只只有 3 个横向相位自由度，而且每通道负载更大；
- 这只是 1D 横向转向原型，不等于已经能做 2D 定点聚焦。

今天先让 4 路全部同相。不要在没有示波器验证 `hpoint` 和更新毛刺前直接尝试相位扫描。

## 2. 今天需要的元件

| 元件 | 数量 | 说明 |
|---|---:|---|
| ESP32-S3 自制开发板 | 1 | GPIO4、5、6、7 |
| TCT40-16T 发射换能器 | 12 | 4 列，每列 3 只并联 |
| TC4428AEPA（DIP-8） | 4 | 每列 1 片 |
| DIP-8 插座 | 4 | 建议使用，先焊插座再插芯片 |
| 10～100 Ω、1/4 W 电阻 | 4 | 每路 GPIO 输入串联；现有10 Ω可用 |
| 10 kΩ、1/4 W 电阻 | 4 | 每路 TC4428 输入下拉 |
| 100 nF、≥25 V 陶瓷电容 | 4 | 每片 TC4428 的近端去耦 |
| 4.7～10 µF、≥25 V 电容 | 4 | 每片 TC4428 的近端储能 |
| 470 µF、≥25 V 电解电容 | 1 | 四路驱动板的 12 V 总入口 |
| 10～22 Ω、0.5 W 电阻 | 4 | 初次上电的输出串联限流/阻尼，可稍降声压 |
| 12 V/5 A 中心正适配器 | 1 | 本次远用不到 5 A，但电压合适 |
| 1～2 A 保险丝和匹配保险丝座 | 1 | 装在驱动板 12 V 分支；只有 5 A 也可先用，但保护较弱 |
| 开关、接线端子、洞洞板、导线 | 若干 | 电源线 18 AWG；逻辑/短输出线 22～24 AWG |

今天不需要：谐振电感、L298N、74HC125N、74LVC125AD、旋转平台、摄像头。短线台架仍按原方案，由 ESP32-S3 的 3.3 V GPIO 直接驱动 TC4428A 输入。现有一片 74AHCT125N 恰好能缓冲 4 路，但为保持本次最小版接线不变，暂不加入；如果后续加入，必须四路一起加入。

## 3. TC4428AEPA 逐针接线

缺口朝上，从左上角 1 脚开始逆时针编号：

```text
             缺口
          ┌────────┐
 NC    1 ─┤        ├─ 8  NC
 IN_A  2 ─┤TC4428A ├─ 7  OUT_A
 GND   3 ─┤        ├─ 6  VDD (+12 V)
 IN_B  4 ─┤        ├─ 5  OUT_B
          └────────┘
```

每一路完全相同：

```text
ESP32 GPIO ──10～100 Ω──┬── pin 2 IN_A
                    ├── pin 4 IN_B
                    └──10 kΩ── GND

12 V ─────────────── pin 6 VDD
GND  ─────────────── pin 3 GND

pin 6 VDD ──||── pin 3 GND    100 nF，贴近芯片
pin 6 VDD ──|(|─ pin 3 GND    4.7～10 µF，电解正极接 VDD

pin 7 OUT_A ──10～22 Ω── 列 A 母线 ──┬── 换能器 1 的 A 脚
                                  ├── 换能器 2 的 A 脚
                                  └── 换能器 3 的 A 脚

pin 5 OUT_B ───────── 列 B 母线 ──┬── 换能器 1 的 B 脚
                                  ├── 换能器 2 的 B 脚
                                  └── 换能器 3 的 B 脚
```

注意：

- pin 2 和 pin 4 必须接同一 GPIO；TC4428A 的两路输出因此互补；
- 换能器接在 `OUT_A` 与 `OUT_B` 之间，**两端都不能接 GND**；
- 串口命令 `0` 只会停止 40 kHz 切换。由于 TC4428A 是互补输出，静态输入时两输出仍可能一高一低；改线必须关闭驱动板 12 V，不能把软件停止当作断电；
- 四列的 A/B 输出母线互不相连；只有 `+12 V` 和 `GND` 共用；
- 12 只换能器朝向一致，同一侧引脚都标为 A；所有引脚都要焊，不靠孔的夹紧力导电；
- 每片芯片的 100 nF 必须贴近 pin 6 和 pin 3，不能只在电源入口放一个大电容；
- 10～22 Ω 先装在 OUT_A 一侧即可。示波器验证稳定后才考虑用 0 Ω 跨接旁路；
- pin 1、pin 8 悬空，不要接任何电源。

## 4. ESP32 到四路驱动的连接表

| 阵面列 | LEDC 通道 | 自制板引脚 | 接到 |
|---|---:|---|---|
| 最左列 CH1 | 0 | H4-4 / GPIO4 | 第 1 片 TC4428A 的 pin 2+4 |
| CH2 | 1 | H4-5 / GPIO5 | 第 2 片 TC4428A 的 pin 2+4 |
| CH3 | 2 | H4-6 / GPIO6 | 第 3 片 TC4428A 的 pin 2+4 |
| 最右列 CH4 | 3 | H4-7 / GPIO7 | 第 4 片 TC4428A 的 pin 2+4 |
| 公共地 | — | H4-22 / GND | 四片 TC4428A 的 pin 3 和驱动电源负极 |

GPIO 线尽量短，旁边配一根 GND；不要让逻辑线和四路差分输出长距离并排。

## 5. 12 V 电源怎么接

推荐电源树：

```text
12 V/5 A 适配器
  └─ DC5521（中心正）
      └─ 总开关/保险丝/星形分配
          ├─ 开发板 DC5521 输入
          └─ 1～2 A 分支保险丝 ── 四片 TC4428A 的 +12 V

适配器负极 ── 开发板 GND ── 四片 TC4428A GND（必须共地）
```

如果今天只有一个插头且来不及做外部分线，可以在万用表确认极性后，暂时从开发板标明的 `12 V 输出` 给这块 12 阵元小驱动板供电。本次负载较小，可以作为台架临时接法；最终 96 阵元不能让主电流经过开发板铜箔。上电前必须确认该端子相对 GND 为约 +12 V。

自制板的 Micro-USB 是 CH340X 烧录/串口链路，不应被当作开发板主电源。烧录时开发板本身也要由 DC5521 或 Type-C PD 电源口正常供电，二者选择一个，不要同时接入。

## 6. 烧录

Arduino IDE 选择：

- 开发板：`ESP32S3 Dev Module`
- Upload Speed：`115200`
- Flash Size：`16MB`
- PSRAM：`8MB / OPI PSRAM`（按当前板包菜单的等价选项）
- USB CDC On Boot：`Disabled`
- 串口：CH340X 对应的 COM 口

打开 `esp32_s3_4x3_min_test.ino`，开发板接 12 V，Micro-USB 接电脑，然后上传。上传后打开 115200 波特率串口监视器。

命令：

| 命令 | 行为 |
|---|---|
| `0` + 回车 | 四路停止切换；改线前仍须切断驱动 12 V |
| `1`～`4` + 回车 | 只开启对应的一列，40 kHz、50% 占空 |
| `A` | 四列同相开启，40 kHz、50% 占空 |
| `T` | 四列同相，运行 1 kHz 正弦包络测试 |
| `20`～`3000` + 回车 | 四列同相，播放输入频率（Hz）的连续正弦包络 |
| `D` | 选择 DSB-AM 音频调制（上电默认） |
| `S` | 选择平方根幅度调制 SRAM |
| `E` | 选择增强响度的软压缩 PCM（上电默认） |
| `R` | 选择原始 PCM 电平，用于与增强模式 A/B 对比 |
| `B` | 纯音/音频选择高调制度包络 0.02～0.98（上电默认） |
| `N` | 纯音/音频选择原调制度包络，用于 A/B 对比 |
| `-` / `[` | 载波降低 100 Hz，最低 38 kHz |
| `+` / `]` | 载波升高 100 Hz，最高 42 kHz |
| `C` | 把载波恢复为 40 kHz |
| `F` | 打印 LEDC 实际载波频率 |
| `P` | 播放固件中的音频一次，播完自动停止 |
| `L` | 循环播放固件中的音频 |
| `H` | 显示帮助 |

上电默认关闭 PWM，不会自动发射。

### 6.1 直接试播内置旋律

当前 `src/data/audio_data.h` 配置了一个由固件生成的约2秒八音测试旋律。烧录后：

1. 先用 `1`～`4` 和 `T` 确认四路硬件正常；
2. 输入 `D` 或 `S` 选择 DSB-AM/SRAM；
3. 输入 `P`，播放测试旋律一次；
4. 输入 `L`，循环播放；
5. 随时输入 `0` 并回车停止。

`A`只发当前设置的连续超声载波，人耳通常听不到。`P/L`会使用最近由`D/S`选择的方式，把音频变成当前载波的幅度包络。切换调制方式不会中断当前播放，而会在下一次`P/L`命令时生效。

`E`在调制前使用查找表进行带底噪门限的软压缩：小信号增益约6倍，接近满幅时逐渐压缩到1，因此不会扩大调制包络峰值。对当前内置PCM，整体RMS由约0.172提高到约0.435，约增加8.1 dB。增强会牺牲部分动态范围并增加失真；发送`R`后重新`P/L`可与原始PCM直接比较。首次测试增强模式时先播放5～10秒并检查驱动器、串联电阻和换能器温升。

`B`把DSB/SRAM音频的峰值包络由0.85提高到0.98，并增大调制深度；理想模型下相对`N`再增加约2.5～2.8 dB。它不改变12 V电源电压，但会提高平均超声输出。`B/N`也选择下一次纯音的包络深度；`N`保留原参数用于回退和对比。

要对比不同可听频率，直接输入整数 Hz 并回车，例如`300`、`500`、`1000`。纯音使用 8 kHz 采样的32位相位累加器和256点正弦表，因此频率不必整除8 kHz。每次测量应保持载波频率、阵列位置、测试距离和`B/N`模式不变；两个频率之间直接再输入新数字即可切换。`T`仍是 1000 Hz 快捷键。

`-/+`可在输出开启时调整载波，便于固定接收位置后扫描响度峰值。LEDC实际可实现的频率会回显，受硬件小数分频量化影响，可能与目标值相差十几赫兹。

### 6.2 换成自己的WAV音频

准备一段尽量短、语音清晰、没有强低音的未压缩PCM WAV。建议先用2～5秒语音，不要一开始放音乐。先在项目根目录执行 `uv sync --locked`，然后在本目录打开 PowerShell 并运行：

```powershell
uv run python ..\..\utils\wav_to_audio_header.py .\我的音频.wav .\src\data\audio_data.h
```

转换器会自动合并为单声道、重采样为8 kHz、转成8位无符号PCM、去除直流、归一化音量并增加短淡入淡出。转换器只接受未压缩PCM WAV，最长30秒；MP3、AAC需要先用音频软件导出为WAV。

生成后重新在Arduino IDE中编译并烧录，再发送 `P`。音频数据烧在ESP32 Flash里，播放时不依赖电脑持续传输；换音频需要重新生成头文件并烧录。8 kHz、8位、单声道每秒约占8 kB Flash。

### 6.3 这个播放功能实际做了什么

这不是普通扬声器的PCM输出，而是实验性的超声包络调制：

```text
8 kHz音频样本 → 正包络 → 改变40 kHz方波基波幅度
→ 四列TC4428差分驱动 → 超声阵列 → 空气非线性自解调
```

当前固件使用 `b=0.45`、`d=0.40`，归一化音频为 `s∈[-1,1]`：

```text
DSB-AM: E = b + d*s
SRAM:   E = sqrt((b+d) * (b+d*s))
PWM:    duty_ratio = asin(E) / pi
```

SRAM 公式是 `sqrt(1+m*s)` 的等比例形式，并缩放到与 DSB-AM 相同的峰值包络 `b+d`。两种方式的实际可听声压仍可能不同，正式比较失真时需要用麦克风实测并校准声压，不能只按数字占空比判断。

12只阵元、约24 Vpp且无谐振升压时，正确调制也可能只能听到很弱或失真的声音。是否听得到不能单独作为电路是否工作的判据。不要把耳朵贴近阵列；测试时让阵面朝向无人区域，先播放5～10秒并检查驱动器和输出电阻温升。

### 6.4 调制计时

调制采样由 40 MHz GPTimer 周期中断驱动，8 kHz 采样率对应 5000 个硬件计数，不依赖 FreeRTOS tick。中断只累计待处理节拍并通知播放任务；如果系统繁忙导致多个节拍积压，播放任务会跳过已经过期的样本以保持音调和总时长。停止或播放完成时若出现过积压，串口会输出：

```text
TIMING WARNING: skipped ... stale samples; max backlog ... ticks
```

40 kHz LEDC 载波显式使用 80 MHz APB 时钟，10-bit 分辨率下的分频值为 `500/256`，可以被硬件精确表示。四路占空比采用“先写四路 shadow 参数、再集中触发更新”的顺序，以缩短通道间更新时间差；最终同步程度仍应使用逻辑分析仪或示波器验证。

## 7. 必须按这个顺序上电

1. 不插 TC4428A、不接换能器，万用表查 +12 V 与 GND 无短路，并确认每个插座 pin 6 是 +12 V、pin 3 是 GND。
2. 只插第 1 片 TC4428A，先不接换能器。发送 `1`，测 GPIO4 为约 40 kHz。
3. 示波器分别测 pin 7 对 GND、pin 5 对 GND，应为约 0～12 V 且互补。
4. 示波器差分测量应使用 CH1/CH2 都以电路 GND 为参考，再做 `CH1-CH2` 数学运算。**不要把示波器地夹夹到 OUT_A 或 OUT_B。**
5. 先接 1 只换能器，工作 10 秒，断电检查 TC4428A 和 10～22 Ω 电阻是否发热。
6. 再扩到该列 3 只；通过后依次复制到 CH2～CH4。
7. 最后才发送 `A`。`T` 只用于包络链路试验，不以“耳朵听见”为通过条件。

理想情况下，12 V 供电的 OUT_A 与 OUT_B 差分接近 24 Vpp，但负载、驱动内阻和 10～22 Ω 电阻会使实测值降低。40 kHz 超声听不见并不代表没有输出；使用示波器加接收型 40 kHz 换能器检查，手机麦克风/分贝 App 不可靠。

## 8. 这版能证明什么、不能证明什么

能证明：

- ESP32-S3 能稳定产生四路 40 kHz；
- TC4428A 的互补差分驱动、电源和 12 只阵面接线正常；
- 四列单独开关和同相合成正常；
- 简单包络能从代码传到超声载波。

不能证明：

- 已经完成语音播放；
- 已经完成定点聚焦或视觉跟踪；
- 12 只、约 24 Vpp 的小阵面一定能产生明显的空气自解调可听声；
- 当前 LEDC 相位更新无毛刺。后续必须用示波器校准，再增加静态相位表。

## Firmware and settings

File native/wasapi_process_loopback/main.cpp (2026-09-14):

#define WIN32_LEAN_AND_MEAN
#include <windows.h>

#include <initguid.h>
#include <audioclient.h>
#include <fcntl.h>
#include <io.h>
#include <mmdeviceapi.h>
#include <mmsystem.h>
#include <objidl.h>
#include <propidl.h>

#include <algorithm>
#include <array>
#include <atomic>
#include <chrono>
#include <cstdint>
#include <cstdio>
#include <cstdlib>
#include <cstring>
#include <vector>

namespace {

// MinGW's Windows headers expose ActivateAudioInterfaceAsync but do not yet
// declare the process-loopback activation payload from recent Windows SDKs.
// Keep the ABI declarations local so this helper remains buildable with the
// toolchain used by this project.
enum class ProcessActivationType : uint32_t {
  kDefault = 0,
  kProcessLoopback = 1,
};

enum class ProcessLoopbackMode : uint32_t {
  kIncludeTargetProcessTree = 0,
  kExcludeTargetProcessTree = 1,
};

struct ProcessLoopbackParameters {
  DWORD targetProcessId;
  ProcessLoopbackMode mode;
};

struct AudioClientActivationParameters {
  ProcessActivationType activationType;
  ProcessLoopbackParameters processLoopbackParameters;
};

constexpr wchar_t kProcessLoopbackDevice[] = L"VAD\\Process_Loopback";
constexpr uint32_t kSampleRate = 48000;
constexpr uint16_t kChannels = 2;
constexpr uint16_t kSampleFormatFloat32 = 1;
constexpr uint32_t kFramesPerBlock = kSampleRate / 100;
constexpr uint32_t kMaximumBufferedFrames = kSampleRate / 10;

#pragma pack(push, 1)
struct StreamHeader {
  char magic[4];
  uint32_t sampleRate;
  uint16_t channels;
  uint16_t sampleFormat;
};
#pragma pack(pop)

static_assert(sizeof(StreamHeader) == 12);

void printError(const char* operation, HRESULT result) {
  std::fprintf(stderr, "%s failed: HRESULT 0x%08lx\n", operation,
               static_cast<unsigned long>(result));
}

bool writeAll(const void* data, size_t size) {
  const auto* cursor = static_cast<const uint8_t*>(data);
  while (size > 0) {
    const size_t written = std::fwrite(cursor, 1, size, stdout);
    if (written == 0) return false;
    cursor += written;
    size -= written;
  }
  return true;
}

class ActivationHandler final : public IActivateAudioInterfaceCompletionHandler {
 public:
  ActivationHandler() : completed_(CreateEventW(nullptr, TRUE, FALSE, nullptr)) {}

  ~ActivationHandler() {
    if (audioClient_ != nullptr) audioClient_->Release();
    if (completed_ != nullptr) CloseHandle(completed_);
  }

  bool valid() const { return completed_ != nullptr; }

  HRESULT wait(IAudioClient** audioClient) {
    if (WaitForSingleObject(completed_, 5000) != WAIT_OBJECT_0) {
      return HRESULT_FROM_WIN32(ERROR_TIMEOUT);
    }
    if (FAILED(result_)) return result_;
    if (audioClient_ == nullptr) return E_UNEXPECTED;
    audioClient_->AddRef();
    *audioClient = audioClient_;
    return S_OK;
  }

  HRESULT STDMETHODCALLTYPE QueryInterface(REFIID iid, void** object) override {
    if (object == nullptr) return E_POINTER;
    *object = nullptr;
    if (IsEqualIID(iid, IID_IUnknown) ||
        IsEqualIID(iid, IID_IActivateAudioInterfaceCompletionHandler) ||
        IsEqualIID(iid, IID_IAgileObject)) {
      *object = static_cast<IActivateAudioInterfaceCompletionHandler*>(this);
      AddRef();
      return S_OK;
    }
    return E_NOINTERFACE;
  }

  ULONG STDMETHODCALLTYPE AddRef() override {
    return static_cast<ULONG>(++references_);
  }

  ULONG STDMETHODCALLTYPE Release() override {
    const ULONG remaining = static_cast<ULONG>(--references_);
    if (remaining == 0) delete this;
    return remaining;
  }

  HRESULT STDMETHODCALLTYPE ActivateCompleted(
      IActivateAudioInterfaceAsyncOperation* operation) override {
    HRESULT activationResult = E_UNEXPECTED;
    IUnknown* activated = nullptr;
    result_ = operation->GetActivateResult(&activationResult, &activated);
    if (SUCCEEDED(result_)) result_ = activationResult;
    if (SUCCEEDED(result_) && activated != nullptr) {
      result_ = activated->QueryInterface(
          IID_IAudioClient, reinterpret_cast<void**>(&audioClient_));
    }
    if (activated != nullptr) activated->Release();
    SetEvent(completed_);
    return S_OK;
  }

 private:
  std::atomic<ULONG> references_{1};
  HANDLE completed_ = nullptr;
  HRESULT result_ = E_PENDING;
  IAudioClient* audioClient_ = nullptr;
};

HRESULT activateProcessLoopback(DWORD processId, ProcessLoopbackMode mode,
                                IAudioClient** audioClient) {
  AudioClientActivationParameters activation = {};
  activation.activationType = ProcessActivationType::kProcessLoopback;
  activation.processLoopbackParameters.targetProcessId = processId;
  activation.processLoopbackParameters.mode = mode;

  PROPVARIANT parameters = {};
  parameters.vt = VT_BLOB;
  parameters.blob.cbSize = sizeof(activation);
  parameters.blob.pBlobData = reinterpret_cast<BYTE*>(&activation);

  auto* handler = new ActivationHandler();
  if (!handler->valid()) {
    handler->Release();
    return HRESULT_FROM_WIN32(GetLastError());
  }

  IActivateAudioInterfaceAsyncOperation* operation = nullptr;
  HRESULT result = ActivateAudioInterfaceAsync(
      kProcessLoopbackDevice, IID_IAudioClient, &parameters, handler,
      &operation);
  if (SUCCEEDED(result)) result = handler->wait(audioClient);
  // The MinGW projection of the async-operation Release call blocks on some
  // Windows 11 builds after successful process-loopback activation. The
  // helper owns a single activation for its process lifetime, so intentionally
  // retain this tiny COM object and let process teardown reclaim it.
  (void)operation;
  handler->Release();
  return result;
}

int capture(DWORD processId, ProcessLoopbackMode mode) {
  IAudioClient* audioClient = nullptr;
  HRESULT result = activateProcessLoopback(processId, mode, &audioClient);
  if (FAILED(result)) {
    printError("ActivateAudioInterfaceAsync", result);
    return 3;
  }

  WAVEFORMATEX format = {};
  format.wFormatTag = WAVE_FORMAT_PCM;
  format.nChannels = kChannels;
  format.nSamplesPerSec = kSampleRate;
  format.wBitsPerSample = 16;
  format.nBlockAlign = format.nChannels * format.wBitsPerSample / 8;
  format.nAvgBytesPerSec = format.nSamplesPerSec * format.nBlockAlign;

  const DWORD flags = AUDCLNT_STREAMFLAGS_LOOPBACK |
                      AUDCLNT_STREAMFLAGS_EVENTCALLBACK |
                      AUDCLNT_STREAMFLAGS_AUTOCONVERTPCM |
                      AUDCLNT_STREAMFLAGS_SRC_DEFAULT_QUALITY;
  result = audioClient->Initialize(AUDCLNT_SHAREMODE_SHARED, flags, 0, 0,
                                   &format, nullptr);
  if (FAILED(result)) {
    printError("IAudioClient::Initialize", result);
    return 4;
  }

  HANDLE sampleReadyEvent = CreateEventW(nullptr, FALSE, FALSE, nullptr);
  if (sampleReadyEvent == nullptr) {
    printError("CreateEventW", HRESULT_FROM_WIN32(GetLastError()));
    return 5;
  }

  result = audioClient->SetEventHandle(sampleReadyEvent);
  if (FAILED(result)) {
    printError("IAudioClient::SetEventHandle", result);
    CloseHandle(sampleReadyEvent);
    return 6;
  }

  IAudioCaptureClient* captureClient = nullptr;
  result = audioClient->GetService(
      IID_IAudioCaptureClient, reinterpret_cast<void**>(&captureClient));
  if (FAILED(result)) {
    printError("IAudioClient::GetService", result);
    CloseHandle(sampleReadyEvent);
    return 7;
  }

  result = audioClient->Start();
  if (FAILED(result)) {
    printError("IAudioClient::Start", result);
    CloseHandle(sampleReadyEvent);
    return 8;
  }

  const StreamHeader header = {{'U', 'P', 'C', 'M'}, kSampleRate,
                               kChannels, kSampleFormatFloat32};
  if (!writeAll(&header, sizeof(header))) {
    audioClient->Stop();
    CloseHandle(sampleReadyEvent);
    return 9;
  }

  std::vector<float> pending;
  size_t pendingOffset = 0;
  std::array<float, kFramesPerBlock * kChannels> output = {};
  auto nextOutput =
      std::chrono::steady_clock::now() + std::chrono::milliseconds(10);
  bool running = true;
  while (running) {
    const DWORD waitResult = WaitForSingleObject(sampleReadyEvent, 1);
    if (waitResult == WAIT_FAILED) {
      printError("WaitForSingleObject", HRESULT_FROM_WIN32(GetLastError()));
      running = false;
      break;
    }

    UINT32 frames = 0;
    if (waitResult == WAIT_OBJECT_0) {
      result = captureClient->GetNextPacketSize(&frames);
      if (FAILED(result)) {
        printError("IAudioCaptureClient::GetNextPacketSize", result);
        running = false;
      }
      if (running && frames > 0) {
        BYTE* data = nullptr;
        DWORD captureFlags = 0;
        UINT64 devicePosition = 0;
        UINT64 qpcPosition = 0;
        result = captureClient->GetBuffer(&data, &frames, &captureFlags,
                                          &devicePosition, &qpcPosition);
        if (FAILED(result)) {
          printError("IAudioCaptureClient::GetBuffer", result);
          running = false;
        }

        if (running) {
          const size_t sampleCount = static_cast<size_t>(frames) * kChannels;
          if ((captureFlags & AUDCLNT_BUFFERFLAGS_DATA_DISCONTINUITY) != 0) {
            pending.clear();
            pendingOffset = 0;
          }
          if ((captureFlags & AUDCLNT_BUFFERFLAGS_SILENT) != 0) {
            pending.insert(pending.end(), sampleCount, 0.0f);
          } else {
            const auto* input = reinterpret_cast<const int16_t*>(data);
            pending.reserve(pending.size() + sampleCount);
            for (size_t index = 0; index < sampleCount; ++index) {
              pending.push_back(static_cast<float>(input[index]) / 32768.0f);
            }
          }
          result = captureClient->ReleaseBuffer(frames);
          if (FAILED(result)) {
            printError("IAudioCaptureClient::ReleaseBuffer", result);
            running = false;
          }
        }
      }
    }

    size_t availableFrames =
        (pending.size() - pendingOffset) / kChannels;
    if (availableFrames > kMaximumBufferedFrames) {
      const size_t droppedFrames = availableFrames - kMaximumBufferedFrames;
      pendingOffset += droppedFrames * kChannels;
      availableFrames = kMaximumBufferedFrames;
    }
    if (pendingOffset > kFramesPerBlock * kChannels * 4) {
      pending.erase(pending.begin(), pending.begin() + pendingOffset);
      pendingOffset = 0;
    }

    const auto now = std::chrono::steady_clock::now();
    if (now >= nextOutput) {
      output.fill(0.0f);
      const size_t copiedFrames =
          std::min<size_t>(availableFrames, kFramesPerBlock);
      const size_t copiedSamples = copiedFrames * kChannels;
      if (copiedSamples > 0) {
        std::copy_n(pending.data() + pendingOffset, copiedSamples,
                    output.data());
      }
      pendingOffset += copiedSamples;
      running = writeAll(output.data(), output.size() * sizeof(float));

      if (now - nextOutput > std::chrono::milliseconds(50)) {
        nextOutput = now + std::chrono::milliseconds(10);
      } else {
        nextOutput += std::chrono::milliseconds(10);
      }
    }
  }

  audioClient->Stop();
  CloseHandle(sampleReadyEvent);
  return running ? 0 : 10;
}

}  // namespace

int main(int argc, char** argv) {
  if (argc != 3 ||
      (std::strcmp(argv[1], "--include-pid") != 0 &&
       std::strcmp(argv[1], "--exclude-pid") != 0)) {
    std::fprintf(stderr,
                 "usage: wasapi_process_loopback "
                 "<--include-pid|--exclude-pid> <pid>\n");
    return 2;
  }

  const unsigned long parsed = std::strtoul(argv[2], nullptr, 10);
  if (parsed == 0 || parsed > UINT32_MAX) {
    std::fprintf(stderr, "invalid process id\n");
    return 2;
  }

  if (_setmode(_fileno(stdout), _O_BINARY) == -1) {
    std::fprintf(stderr, "failed to put stdout in binary mode\n");
    return 2;
  }
  std::setvbuf(stdout, nullptr, _IONBF, 0);

  const HRESULT initialized =
      CoInitializeEx(nullptr, COINIT_MULTITHREADED);
  if (FAILED(initialized)) {
    printError("CoInitializeEx", initialized);
    return 2;
  }

  const ProcessLoopbackMode mode =
      std::strcmp(argv[1], "--include-pid") == 0
          ? ProcessLoopbackMode::kIncludeTargetProcessTree
          : ProcessLoopbackMode::kExcludeTargetProcessTree;
  timeBeginPeriod(1);
  const int result = capture(static_cast<DWORD>(parsed), mode);
  timeEndPeriod(1);
  CoUninitialize();
  return result;
}

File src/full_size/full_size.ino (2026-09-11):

#include <Arduino.h>

#include "src/app/ultrasonic_app.h"
#include "src/driver/ultrasonic_driver.h"

namespace {

ultrasonic::UltrasonicDriver gDriver;
ultrasonic::UltrasonicApp gApp(gDriver);

void reportStartupError(const char* stage, esp_err_t error) {
  Serial.printf("STARTUP ERROR (%s): %s\r\n", stage,
                esp_err_to_name(error));
  Serial.println("GPIO4 switching remains OFF.");
}

}  // namespace

void setup() {
#if !ARDUINO_USB_CDC_ON_BOOT
  // HardwareSerial defaults to 256 bytes, barely more than one 185-byte
  // AUDIO_DATA frame. Leave room for queued host packets and control-task jitter.
  // This UART ring is separate from the 2048-sample decoded audio buffer.
  Serial.setRxBufferSize(4096);
#endif
  Serial.begin(460800);
  delay(300);

  const esp_err_t driverError = gDriver.begin();
  if (driverError != ESP_OK) {
    reportStartupError("single-GPIO carrier driver", driverError);
    return;
  }

  const esp_err_t appError = gApp.begin();
  if (appError != ESP_OK) {
    gDriver.stop();
    reportStartupError("FreeRTOS playback manager", appError);
  }
}

void loop() {
  // Serial control and modulation playback run in FreeRTOS tasks.
  vTaskDelay(pdMS_TO_TICKS(1000));
}

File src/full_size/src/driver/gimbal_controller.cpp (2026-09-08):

#include "gimbal_controller.h"

namespace ultrasonic {

uint32_t GimbalController::angleToDuty(int32_t logicalDegrees,
                                       int32_t direction) {
  const int32_t directedDegrees = logicalDegrees * direction;
  const int32_t pulseMicroseconds =
      static_cast<int32_t>(kCenterPulseMicroseconds) +
      directedDegrees *
          static_cast<int32_t>(kMaximumPulseMicroseconds -
                               kMinimumPulseMicroseconds) /
          (kMaximumAngle - kMinimumAngle);

  return static_cast<uint32_t>(
      (static_cast<uint64_t>(pulseMicroseconds) * kPeriodCounts +
       kPeriodMicroseconds / 2) /
      kPeriodMicroseconds);
}

esp_err_t GimbalController::begin() {
  if (initialized_) return ESP_OK;

  // Hold both signal pins low until the 50 Hz timer is configured.
  pinMode(kPanGpio, OUTPUT);
  pinMode(kTiltGpio, OUTPUT);
  digitalWrite(kPanGpio, LOW);
  digitalWrite(kTiltGpio, LOW);

  ledc_timer_config_t timerConfig = {};
  timerConfig.speed_mode = kSpeedMode;
  timerConfig.duty_resolution = kResolution;
  timerConfig.timer_num = kTimer;
  timerConfig.freq_hz = kServoFrequencyHz;
  timerConfig.clk_cfg = LEDC_USE_APB_CLK;

  esp_err_t error = ledc_timer_config(&timerConfig);
  if (error != ESP_OK) return error;

  ledc_channel_config_t channelConfig = {};
  channelConfig.speed_mode = kSpeedMode;
  channelConfig.intr_type = LEDC_INTR_DISABLE;
  channelConfig.timer_sel = kTimer;
  channelConfig.hpoint = 0;
  channelConfig.flags.output_invert = 0;
  channelConfig.duty = angleToDuty(0, 1);

  channelConfig.gpio_num = kPanGpio;
  channelConfig.channel = kPanChannel;
  error = ledc_channel_config(&channelConfig);
  if (error != ESP_OK) return error;

  channelConfig.gpio_num = kTiltGpio;
  channelConfig.channel = kTiltChannel;
  error = ledc_channel_config(&channelConfig);
  if (error != ESP_OK) return error;

  initialized_ = true;
  return setAngles(0, 0);
}

esp_err_t GimbalController::setAngles(int32_t panDegrees,
                                      int32_t tiltDegrees) {
  if (!initialized_) return ESP_ERR_INVALID_STATE;
  if (panDegrees < kMinimumAngle || panDegrees > kMaximumAngle ||
      tiltDegrees < kMinimumAngle || tiltDegrees > kMaximumAngle) {
    return ESP_ERR_INVALID_ARG;
  }

  esp_err_t error = writeChannel(
      kPanChannel, angleToDuty(panDegrees + kPanCompensationDegrees, kPanDirection));
  if (error != ESP_OK) return error;

  error = writeChannel(
      kTiltChannel, angleToDuty(tiltDegrees + kTiltCompensationDegrees, kTiltDirection));
  if (error != ESP_OK) return error;

  panDegrees_ = panDegrees;
  tiltDegrees_ = tiltDegrees;
  return ESP_OK;
}

esp_err_t GimbalController::writeChannel(ledc_channel_t channel,
                                         uint32_t duty) {
  esp_err_t error = ledc_set_duty(kSpeedMode, channel, duty);
  if (error != ESP_OK) return error;
  return ledc_update_duty(kSpeedMode, channel);
}

}  // namespace ultrasonic

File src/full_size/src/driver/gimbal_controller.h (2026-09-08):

#pragma once

#include <Arduino.h>
#include "driver/ledc.h"
#include "esp_err.h"

namespace ultrasonic {

// MG996R two-axis gimbal driver. Logical 0 degrees is the 1.5 ms servo
// midpoint; commands use signed angles in the range -90..90 degrees.
class GimbalController final {
 public:
  static constexpr int kTiltGpio = 5;
  static constexpr int kPanGpio = 6;
  static constexpr int32_t kMinimumAngle = -90;
  static constexpr int32_t kMaximumAngle = 90;
  static constexpr int32_t kPanCompensationDegrees = 112;
  static constexpr int32_t kTiltCompensationDegrees = 12;
  esp_err_t begin();
  esp_err_t setAngles(int32_t panDegrees, int32_t tiltDegrees);

  int32_t panDegrees() const { return panDegrees_; }
  int32_t tiltDegrees() const { return tiltDegrees_; }

 private:
  static constexpr ledc_mode_t kSpeedMode = LEDC_LOW_SPEED_MODE;
  static constexpr ledc_timer_t kTimer = LEDC_TIMER_1;
  static constexpr ledc_timer_bit_t kResolution = LEDC_TIMER_14_BIT;
  static constexpr ledc_channel_t kPanChannel = LEDC_CHANNEL_1;
  static constexpr ledc_channel_t kTiltChannel = LEDC_CHANNEL_2;
  static constexpr uint32_t kServoFrequencyHz = 50;
  static constexpr uint32_t kPeriodCounts = 1U << 14;
  static constexpr uint32_t kPeriodMicroseconds = 20000;
  static constexpr uint32_t kMinimumPulseMicroseconds = 1000;
  static constexpr uint32_t kCenterPulseMicroseconds = 1500;
  static constexpr uint32_t kMaximumPulseMicroseconds = 2000;

  // Change either value to -1 if that axis moves opposite to the desired
  // logical direction after the servos are mounted.
  static constexpr int32_t kPanDirection = 1;
  static constexpr int32_t kTiltDirection = 1;

  static uint32_t angleToDuty(int32_t logicalDegrees,
                              int32_t direction);
  esp_err_t writeChannel(ledc_channel_t channel, uint32_t duty);

  bool initialized_ = false;
  int32_t panDegrees_ = 0;
  int32_t tiltDegrees_ = 0;
};

}  // namespace ultrasonic

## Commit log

2026-08-13 发布超声定向音响原型资料
2026-08-14 For more precise tasks, a system timer was adopted, and some timing bugs were fixed.
2026-08-22 Improve ultrasonic modulation and test controls
2026-08-30 Document 120-element single-GPIO wiring
2026-08-30 硬件文件夹
2026-08-30 蜂窝板正面3D打印文件
    [蜂窝阵面前.STL]
2026-09-01 add data flow
2026-09-02 README修改
    Update the last update date and correct the array size in the project overview.
2026-09-04 Add new file 1 in hardware/STL directory
2026-09-04 Add files via upload
    底座blend文件
    [base.blend]
2026-09-07 add track upside function
2026-09-08 adjust some velocity parameters
2026-09-14 Fixed a bug where Windows API blocking caused a timeout and interrupted the audio stream.
    [main.cpp]
2026-09-24 add PerId track
